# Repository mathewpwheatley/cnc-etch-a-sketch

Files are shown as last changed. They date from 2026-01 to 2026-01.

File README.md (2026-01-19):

# CNC Etch-A-Sketch

A CNC-controlled Etch-A-Sketch that automatically draws pre-programmed designs using stepper motors. Built with Arduino and PlatformIO.

<center>
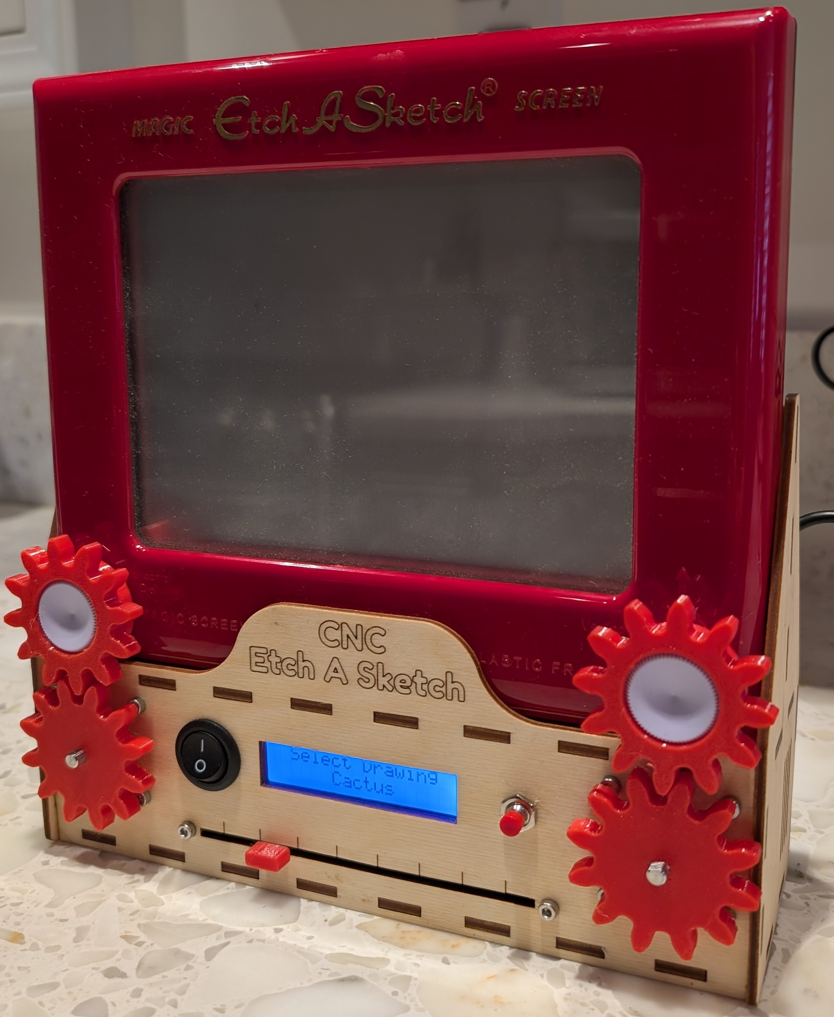
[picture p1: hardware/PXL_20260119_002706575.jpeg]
CNC Etch-A-Sketch
    
</center>

## Overview

This project transforms a classic Etch-A-Sketch toy into an automated drawing machine. An Arduino Nano controls two stepper motors (one for each axis) to precisely manipulate the knobs and draw various patterns. Users can select from multiple pre-programmed designs using a potentiometer and trigger the drawing with a button.

## Features

- **Automated Drawing**: Pre-programmed designs executed with precise stepper motor control
- **Drawing Selection**: Choose from multiple designs using a potentiometer slider
- **State Machine Architecture**: Clean separation of concerns with states for selecting, homing, drawing, and finishing
- **LCD Display**: Real-time feedback on the 16x2 I2C LCD display
- **Stepper Calibration**: Built-in tuning mode for backlash compensation stored in EEPROM

## Bill of Materials (BOM)

### General

| Quantity | Component | Description | Link |
|---|---|---|---|
| 1 | Etch-A-Sketch | Classic Etch-A-Sketch toy | [778988609583](https://www.amazon.com/Etch-A-Sketch-Classic-Red/dp/B01N1ZVYDM/) |

### Electronics

| Quantity | Component | Description | Link |
|---|---|---|---|
| 1 | Arduino Nano | ATmega328P microcontroller | [Arduino Nano V3.0](https://www.amazon.com/dp/B09DCV5HRM) |
| 2 | Stepper Motor | 28BYJ-48 or equivalent (200 steps/rev) | [NEMA 17-34MM](https://www.amazon.com/dp/B0CMSYY6MK) |
| 2 | Motor Driver | L298N dual H-bridge driver | [762917148410](https://www.amazon.com/dp/B0C5JCF5RS) |
| 1 | LCD Display | 16x2 LCD module with I2C backpack | [LCD1602](https://www.amazon.com/dp/B08MPTND1V) |
| 1 | Push Button | Momentary tactile switch | [Cylewet SPST](https://www.amazon.com/dp/B0752RMB7Q) |
| 1 | Linear Potentiometer | Linear 10kΩ potentiometer | [a21031100ux0167](https://www.amazon.com/dp/B0993BXDSC) |
| 1 | Power Switch | Rocker switch 2P1T | [KCD1-105-2P](https://www.amazon.com/dp/B07D285PLL) |
| 1 | DC Power Jack | 5.5mm x 2.1mm DC barrel plug | [DC099-20M889B](https://www.amazon.com/dp/B07C46XMPT) |
| 1 | Power Supply | 12V 5A AC to DC power supply | [4342705952](https://www.amazon.com/dp/B07GFFG1BQ) |

### 3D Printed Parts

All STL files are located in the `hardware/` directory.

| Quantity | Part | Filename |
|---|---|---|
| 2 | Etch-A-Sketch Gear | `gear_0.stl` |
| 2 | Stepper Motor Gear | `gear_1.stl` |
| 1 | Potentiometer Knob | `knob_potentiometer.stl` |
| 2 | Back Mount | `mount_back.stl` |
| 2 | L298N Driver Mount | `mount_L298N.stl` |
| 1 | LCD Mount | `mount_lcd.stl` |

### Laser Cut Parts

All files are located in the `hardware/` directory.

| Quantity | Part | Filename |
|---|---|---|
| 1 | Case Panels | `cnc_etch_a_sketch_case.svg` |

### Hardware (Fasteners)

| Quantity | Component | Description | Link |
|---|---|---|---|
| 10 | Heat-set Inserts | M3 x 4mm | [Assorted knurled threaded inserts](https://www.amazon.com/dp/B07GLJ7KCJ) |
| 10 | Machine Screws | M3 x 6mm | [Assorted Socket Screws](https://www.amazon.com/dp/B014OO5KQG) |
| 8 | Machine Screws | M3 x 10mm (For mounting stepper motors) | [Assorted Socket Screws](https://www.amazon.com/dp/B014OO5KQG) |

### CAD Files

The complete CAD model is available in `hardware/CNC_Etch_A_Sketch.f3d` (Fusion 360 format).

### Pin Connections

**LCD Display (I2C):**
- SDA → A4
- SCL → A5

**Controls:**
- Button → A0
- Potentiometer → A1

**X-Axis Stepper:**
- Pins 8, 7, 6, 5

**Y-Axis Stepper:**
- Pins 12, 11, 10, 9

See `hardware/cnc_etch_a_sketch_wiring_diagram.pdf` and `hardware/EtchASketch.kicad_sch` for the complete wiring diagram and schematic.

## Assembly

### 1. Fabrication

- **3D Printing**: Print all parts from `hardware/*.stl` using PLA or PETG
- **Laser Cutting**: Cut case panels from `hardware/cnc_etch_a_sketch_case.svg` (material: acrylic or wood, thickness: 1/8" (3mm) )
- **Hardware**: Install heat-set inserts into printed parts as needed

### 2. Mechanical Assembly

1. Add heat-set inserts into the holes of all printed parts with a soldering iron.
1. Assemble case by aligning all finger joints, use glue as needed.
1. Mount stepper motors into front panel using screws.
1. Install gears onto stepper motor shafts and Etch-A-Sketch knobs.
1. Glue or epoxy the L298N mounts, LCD mount, and back panel mounts to case panels.
1. Install Arduino Nano, motor drivers, LCD, and controls in respective mounts
1. Follow the wiring diagram in `hardware/cnc_etch_a_sketch_wiring_diagram.pdf` to connect all components.

## Software Requirements

- [PlatformIO](https://platformio.org/) (recommended) or Arduino IDE
- PlatformIO Core (CLI) or PlatformIO IDE extension for VSCode

## Software Setup

### 1. Clone and Install Dependencies

```bash
git clone https://github.com/mathewpwheatley/cnc-etch-a-sketch
cd cnc-etch-a-sketch
pio pkg install
```

### 2. Configure Machine Parameters

Edit `include/config.h` to match your machine dimensions and calibration:

```cpp
constexpr float STEPS_PER_INCH = 140.0f;      // Calibrated steps per inch
constexpr float MACHINE_WIDTH_IN = 6.0f;      // Drawing area width
constexpr float MACHINE_HEIGHT_IN = 4.25f;    // Drawing area height
```

### 3. Build and Upload

```bash
pio run --target upload
```

Or use the PlatformIO IDE upload button.

## Usage

1. **Power On**: The LCD displays "CNC Etch-A-Sketch"
2. **Select Drawing**: Slide the potentiometer to browse available designs
3. **Start Drawing**: Press the button to begin the selected drawing
    1. **Tune Backlash**: Long press the button to enter Tuning mode
    1. **Set Backlash Compensation**: Slide the potentiometer to select the desired compensation and press the button to accept.
4. **Homing**: Manually home to the origin (bottom-left)
5. **Drawing**: Watch as the design is automatically drawn
6. **Finish**: The machine completes and returns to selection mode

### State Flow

```mermaid
graph TD;
    Reset-->Selecting;
    Selecting-->Homing;
    Selecting-->Tuning;
    Tuning-->Selecting;
    Homing-->Drawing;
    Drawing-->Finish;
    Finish-->Reset;
```

Hold the button during operation to interrupt and reset.

## Configuration

### Adding New Drawings

New drawings can be added using the SVG-to-Arduino conversion script:

1. **Create/Add SVG**: Place your SVG file in the `scripts/` directory
   - Keep designs simple - the Arduino Nano has limited memory
   - Use only paths (no fills, gradients, or complex styling)
   - Remember the Etch-A-Sketch can only draw in one continuous line

2. **Run Conversion Script**: Execute the Python script to generate Arduino-compatible code:
   ```bash
   cd scripts
   python svg_to_arduino.py
   ```

3. **Rebuild and Upload**: The script automatically generates `src/drawing/drawing_data.h` with normalized coordinates (0.0 to 1.0). Rebuild and upload the firmware.

**Script Requirements:**
- Python 3
- `svgpathtools` library: `pip install svgpathtools`

The script converts SVG paths into point arrays, normalizes coordinates based on the page dimensions, and handles both straight lines and curves through adaptive sampling.

### Tuning Backlash Compensation

The system includes a tuning state for backlash compensation. Backlash values are stored in EEPROM and persist between power cycles. To use, hold the button for 1 second while in the **Select Drawing** state to enter **Tuning** mode. Use the slide potentiometer to set the desired backlash compensation and press the button again to accept.

### Performance Tuning

Adjust stepper motor parameters in `include/config.h`:

```cpp
constexpr int STEPPER_MAX_SPEED = 1000;           // Steps per second
constexpr int STEPPER_ACCELERATION = 500;         // Steps per second²
```

## Project Structure

```
├── include/
│   └── config.h              # Hardware configuration and constants
├── src/
│   ├── main.cpp              # Entry point
│   ├── Machine.cpp/h         # Main state machine controller
│   ├── drawing/              # Drawing management and data
│   │   └── drawing_data.h   # Generated drawing coordinates (auto-generated)
│   ├── hardware/             # Hardware abstraction (Button, Display, Steppers, Slider)
│   └── state/                # State machine implementations
├── scripts/
│   ├── svg_to_arduino.py     # SVG to Arduino coordinate converter
│   └── *.svg                 # Source SVG drawings
├── hardware/                 # CAD files and fabrication
│   ├── *.stl                 # 3D printable parts
│   ├── *.svg                 # Laser cut files
│   ├── *.f3d                 # Fusion 360 source
│   ├── *.pdf                 # Wiring diagram
│   └── *.kicad_sch           # KiCad schematic
└── platformio.ini            # PlatformIO configuration
```

## Dependencies

- [LiquidCrystal_I2C](https://github.com/marcoschwartz/LiquidCrystal_I2C) (v1.1.4) - I2C LCD control
- [AccelStepper](https://github.com/waspinator/AccelStepper) (v1.64) - Stepper motor acceleration library

## License

This project is licensed under the MIT License, see the [LICENSE](LICENSE) file for details.

## Acknowledgments

Built with Arduino and PlatformIO for precise stepper motor control and clean embedded C++ architecture.

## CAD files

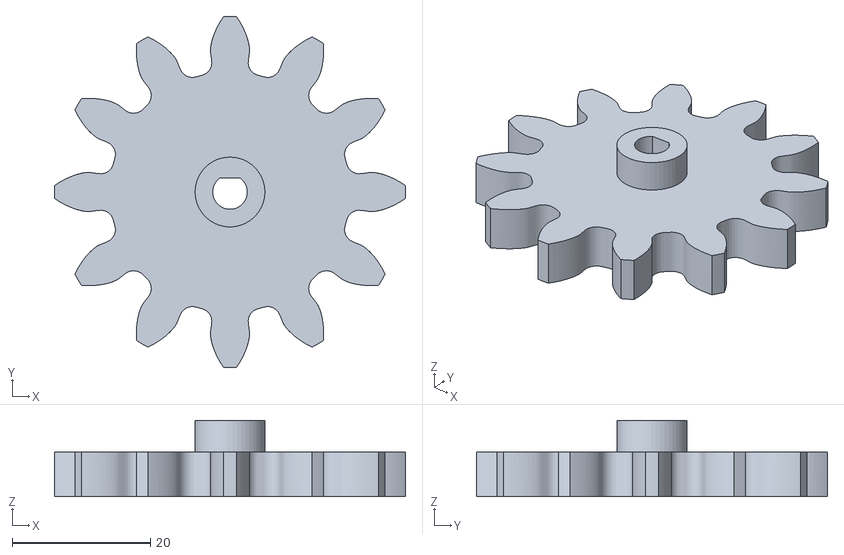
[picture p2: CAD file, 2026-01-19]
hardware/gear_1.stl
50.7 x 50.7 x 11.0

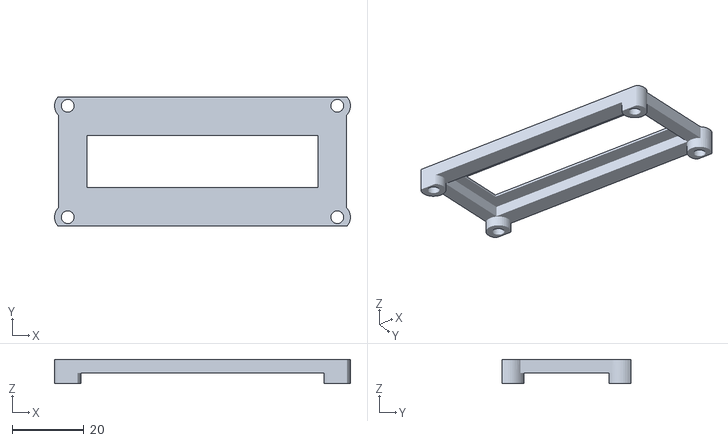
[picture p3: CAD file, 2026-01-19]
hardware/mount_lcd.stl
82.4 x 36.0 x 6.81

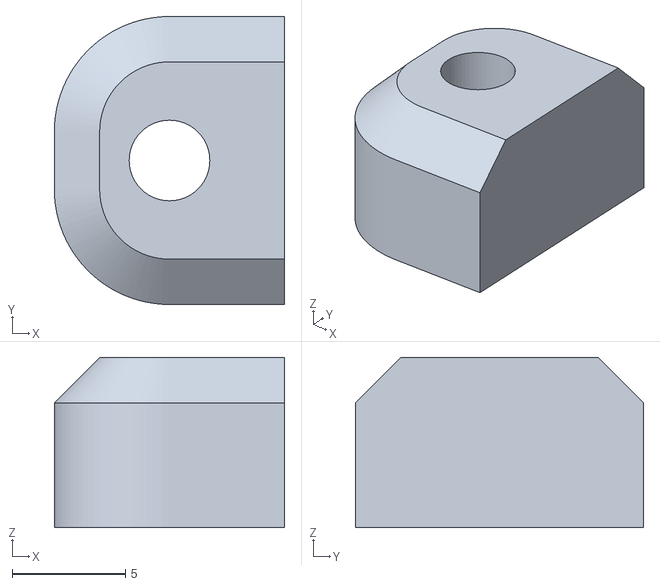
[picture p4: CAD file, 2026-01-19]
hardware/mount_back.stl
10.2 x 12.7 x 7.50

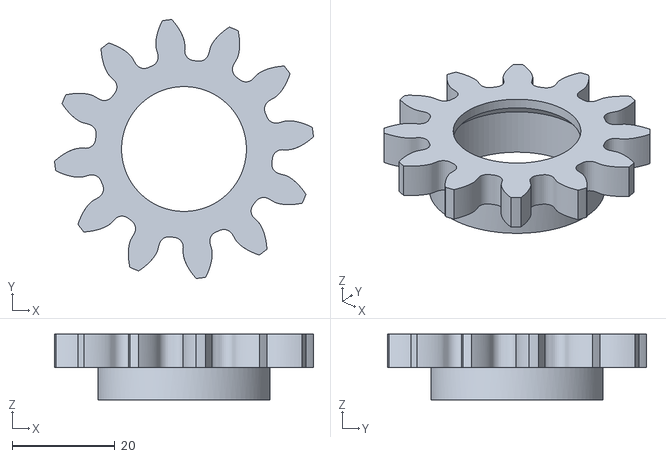
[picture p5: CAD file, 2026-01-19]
hardware/gear_0.stl
50.5 x 50.5 x 12.8

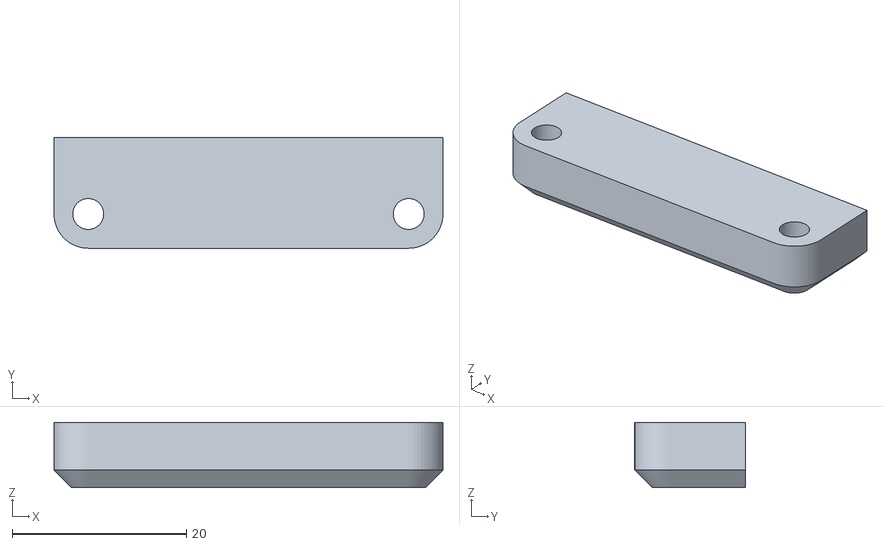
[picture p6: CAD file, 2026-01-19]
hardware/mount_L298N.stl
44.7 x 12.7 x 7.50

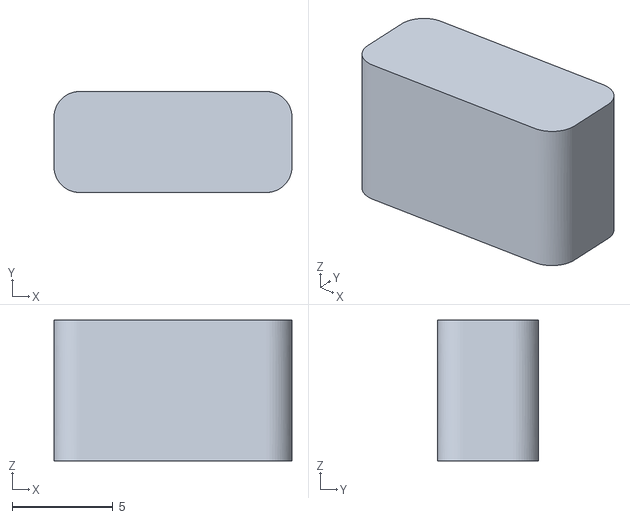
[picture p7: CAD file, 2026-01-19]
hardware/knob_potentiometer.stl
11.8 x 5.01 x 6.99

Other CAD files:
hardware/CNC_Etch_A_Sketch.f3d

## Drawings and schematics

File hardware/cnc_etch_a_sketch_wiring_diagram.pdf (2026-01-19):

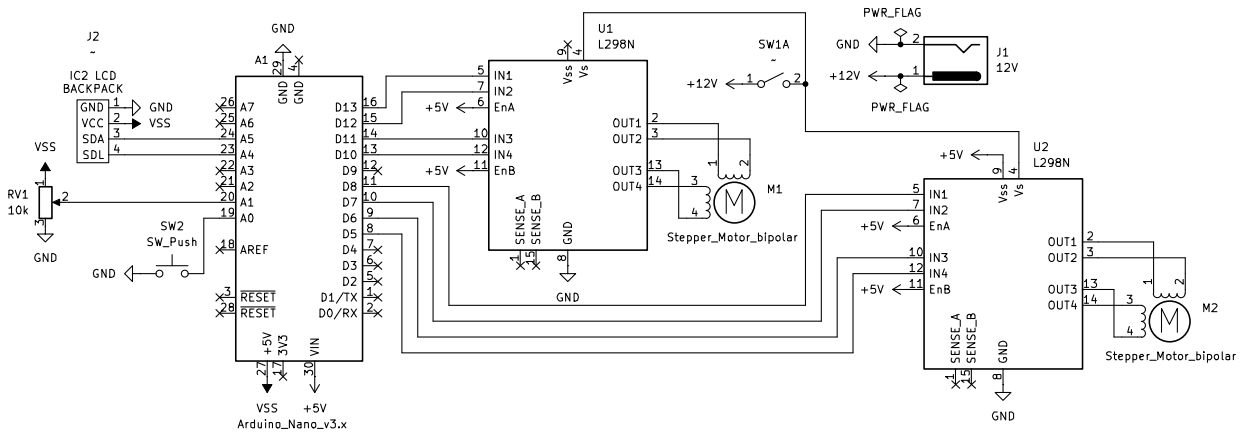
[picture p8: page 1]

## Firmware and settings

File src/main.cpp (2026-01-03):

#include <Arduino.h>
#include "config.h"
#include "Machine.h"

Button button{BTN_PIN};
Slider slider{POT_PIN};
Display display{LCD_ADDRESS, LCD_COLUMNS, LCD_ROWS};
AccelStepper stepperX{AccelStepper::FULL4WIRE, X_PIN1, X_PIN2, X_PIN3, X_PIN4};
AccelStepper stepperY{AccelStepper::FULL4WIRE, Y_PIN1, Y_PIN2, Y_PIN3, Y_PIN4};
Steppers steppers{stepperX, stepperY, STEPPER_MAX_SPEED, STEPPER_ACCELERATION, STEPPER_STEPS_PER_ROTATION, STEPPER_BACKLASH_EEPROM_ADDRESS};
Dimensions dimensions{MACHINE_WIDTH_IN, MACHINE_HEIGHT_IN, STEPS_PER_INCH};

Machine machine(button, slider, display, steppers, dimensions);

void setup()
{
  Serial.begin(9600);
  machine.initialize();

  display.print("CNC", "Etch-A-Sketch");
  delay(2500);
}

void loop()
{
  machine.run();
}

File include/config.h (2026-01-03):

#pragma once

#include <Arduino.h>

// --- Physical Machine Constraints ---
constexpr float STEPS_PER_INCH = 140.0f;
constexpr float MACHINE_WIDTH_IN = 6.0f;
constexpr float MACHINE_HEIGHT_IN = 4.25f;
constexpr long MAX_X = static_cast<long>(MACHINE_WIDTH_IN * STEPS_PER_INCH);
constexpr long MAX_Y = static_cast<long>(MACHINE_HEIGHT_IN * STEPS_PER_INCH);

// --- LCD Constants ---
// Wiring: SDA pin is connected to A4 and SCL pin to A5
constexpr uint8_t LCD_ADDRESS = 0x27;
constexpr uint8_t LCD_COLUMNS = 16;
constexpr uint8_t LCD_ROWS = 2;

// --- Pin Definitions ---
constexpr uint8_t BTN_PIN = A0;
constexpr uint8_t POT_PIN = A1;

constexpr uint8_t X_PIN1 = 8;
constexpr uint8_t X_PIN2 = 7;
constexpr uint8_t X_PIN3 = 6;
constexpr uint8_t X_PIN4 = 5;

constexpr uint8_t Y_PIN1 = 12;
constexpr uint8_t Y_PIN2 = 11;
constexpr uint8_t Y_PIN3 = 10;
constexpr uint8_t Y_PIN4 = 9;

// --- Stepper Motor Tuning ---
constexpr int STEPPER_MAX_SPEED = 1000;
constexpr int STEPPER_ACCELERATION = STEPPER_MAX_SPEED/2;
constexpr int STEPPER_STEPS_PER_ROTATION = 200;

// --- Memory Management ---
constexpr int STEPPER_BACKLASH_EEPROM_ADDRESS = 0;

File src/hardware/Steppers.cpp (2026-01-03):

#include <EEPROM.h>
#include "hardware/Steppers.h"

Steppers::Steppers(
    AccelStepper &stepperX,
    AccelStepper &stepperY,
    float maxSpeed,
    float acceleration,
    int stepsPerRotation,
    int backlashEepromAddress) : _stepperX(stepperX),
                                 _stepperY(stepperY),
                                 _stepsPerRotation(stepsPerRotation),
                                 _backlashEepromAddress(backlashEepromAddress)
{
  _stepperX.setMaxSpeed(maxSpeed);
  _stepperY.setMaxSpeed(maxSpeed);
  _stepperX.setAcceleration(acceleration);
  _stepperY.setAcceleration(acceleration);
};

void Steppers::initialize()
{
  int value;
  EEPROM.get(_backlashEepromAddress, value);
  _backlash = value;
}

void Steppers::setEnabled(bool enable)
{
  if (enable)
  {
    _stepperX.enableOutputs();
    _stepperY.enableOutputs();
  }
  else
  {
    _stepperX.disableOutputs();
    _stepperY.disableOutputs();
  }
}

void Steppers::moveTo(long absoluteX, long absoluteY)
{
  if (_isStopped)
    return;

  _stepperX.moveTo(_applyBacklash(absoluteX, Axis::X));
  _stepperY.moveTo(_applyBacklash(absoluteY, Axis::Y));
  _axes[static_cast<int>(Axis::X)].position = absoluteX;
  _axes[static_cast<int>(Axis::Y)].position = absoluteY;
}

long Steppers::_applyBacklash(long absoluteTarget, Axis axis)
{
  AxisState &a = _axes[static_cast<int>(axis)];
  bool movePositive = (absoluteTarget >= a.position);
  if (absoluteTarget == a.position || movePositive == a.lastMovePositive)
  {
    return absoluteTarget;
  }
  a.lastMovePositive = movePositive;
  return movePositive ? (absoluteTarget + _backlash) : (absoluteTarget - _backlash);
}

void Steppers::resume()
{
  _isStopped = false;
  setEnabled();
}

void Steppers::setHome()
{
  _stepperX.setCurrentPosition(0);
  _stepperY.setCurrentPosition(0);
}

bool Steppers::isRunning()
{
  return _stepperX.isRunning() || _stepperY.isRunning();
}

void Steppers::run()
{
  _stepperX.run();
  _stepperY.run();
}

void Steppers::stop()
{
  _isStopped = true;
  _stepperX.stop();
  _stepperY.stop();
}

int Steppers::getBacklash()
{
  return _backlash;
}

void Steppers::setBacklash(long steps)
{
  _backlash = steps;
  EEPROM.put(_backlashEepromAddress, _backlash);
}

int Steppers::stepsToDegree(long steps)
{
  return (int)((static_cast<long>(steps) * 360) / _stepsPerRotation);
}

long Steppers::degreesToSteps(int degrees)
{
  return (static_cast<long>(degrees) * _stepsPerRotation) / 360;
}

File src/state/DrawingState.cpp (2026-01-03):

#include "state/DrawingState.h"
#include "Machine.h"

void DrawingState::onEntry(Machine &machine)
{
  char message[20];
  const char *name = machine._DrawingManager.get().name;
  snprintf(message, sizeof(message), "Draw: %s", name);
  machine._display.print(message, "");

  _segment = 0;
  machine._steppers.resume();
  machine._steppers.setHome();
}

void DrawingState::update(Machine &machine)
{
  machine.maybeStop();
  if (machine._steppers.isRunning()) {
    machine._steppers.run();
    return;
  }

  const int count = machine._DrawingManager.get().count;
  if (_segment >= count)
  {
    return machine.transitionTo(machine._finishState);
  }

  _setTarget(machine);
  int progress = (_segment * 100) / count;
  machine._display.drawProgressBar(progress);
  return;
}

void DrawingState::_setTarget(Machine &machine) {
  const Drawing &drawing = machine._DrawingManager.get();
  float normX = pgm_read_float(&(drawing.path[_segment][0]));
  float normY = pgm_read_float(&(drawing.path[_segment][1]));

  const Offsets &offsets = machine._offsets;
  long targetX = (long)((normX * offsets.scale) + offsets.offsetX);
  long targetY = (long)((normY * offsets.scale) + offsets.offsetY);

  machine._steppers.moveTo(targetX, targetY);
  _segment++;
}

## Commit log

2026-01-03 fix: :bug: Only correct backlash if axes is changing position
    [Steppers.cpp]
2026-01-19 docs: :memo: Add all hardware files and a readme
    [CNC_Etch_A_Sketch.f3d, EtchASketch.kicad_sch, gear_0.stl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]
